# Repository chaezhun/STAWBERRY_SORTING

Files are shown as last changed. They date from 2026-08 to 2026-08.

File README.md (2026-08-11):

# Strawberry Sorting System

> Three embedded boards — different chips, different operating systems, different languages —
> tied into one sorting line.

A camera and an NPU classify strawberries moving along a conveyor as fresh, unripe or rotten,
and a rotating plate at the end of the belt discharges each class. The communication chain —
Ethernet TCP → IPC shared memory → CAN — was designed from scratch, and at two frames per
second with frequent misdetections the line still actuates **exactly once per strawberry**.
The whole line starts from a single SSH command; no UART cables remain.

[한국어](README.ko.md)

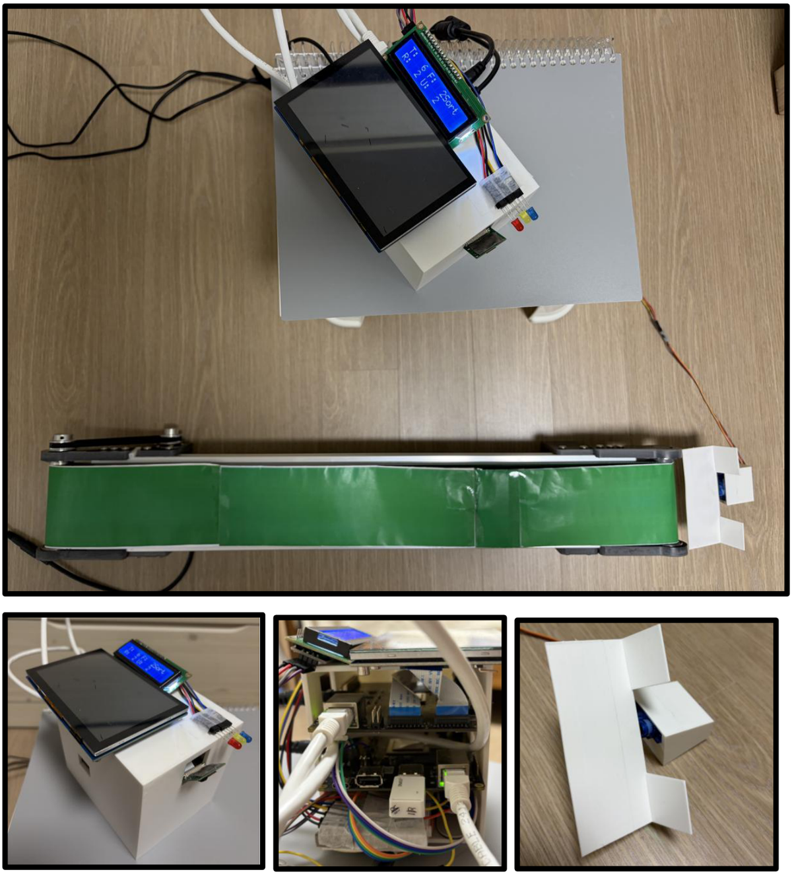
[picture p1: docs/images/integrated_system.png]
The assembled system — conveyor, rotation plate, control tower and status LCD


---

## Contents

- [Background](#background)
- [System](#system)
- [Design](#design)
- [Repository structure](#repository-structure)
- [Results](#results)
- [Build and run](#build-and-run)
- [Notes](#notes)

## Background

Each board owns a different layer. Recognition belongs on the NPU, decisions on Linux,
actuation on a real-time MCU. The problem was that the three can only speak in different ways.

AI-G runs a minimal Yocto image with no Python at all. D3-G has two cores running different
operating systems that must communicate through shared memory. VCP-G only accepts CAN frames.
Every hop uses a different mechanism, and making them mesh was most of the work.

## System

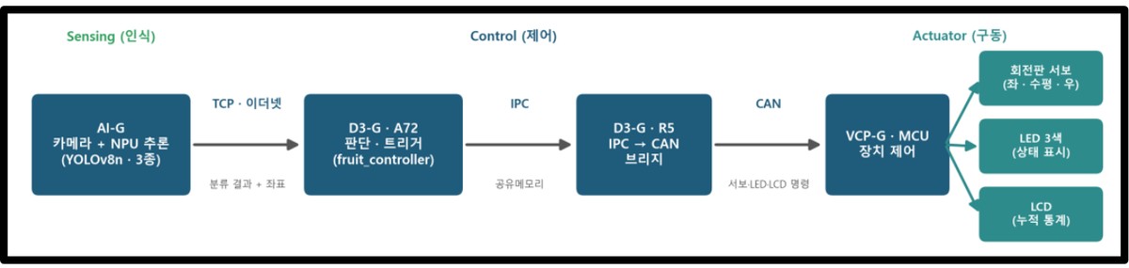
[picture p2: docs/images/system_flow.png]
End-to-end flow — the data path across the recognition, control and actuation boards


```
 camera --> [ AI-G ]  --Ethernet TCP-->  [ D3-G A72 ]
            YOLOv8n on                    classification gating, actuation timing
            the NPU                               |
                                                  | IPC shared memory
                                                  v
                                         [ D3-G R5, FreeRTOS ]
                                                  |
                                                  | CAN bus
                                                  v
                                         [ VCP-G ]  servo, LEDs, LCD
```

| Board | Role | Configuration |
|---|---|---|
| AI-G | Recognition | camera + NPU (8 TOPS), Yocto Linux, YOLOv8n |
| D3-G | Control | A72 (Linux) decides, R5 (FreeRTOS) relays shared memory onto CAN |
| VCP-G | Actuation | TCC70xx MCU, servo, three-colour LEDs, LCD |

With no Python on AI-G, result transmission is written in `sh` + `awk` + `nc`. The two D3-G
cores talk over `/dev/tcc_ipc_micom`, and from there to the actuation board it is CAN — one
byte for the servo angle, two for the LEDs, four for the LCD counter.

### Recognition model

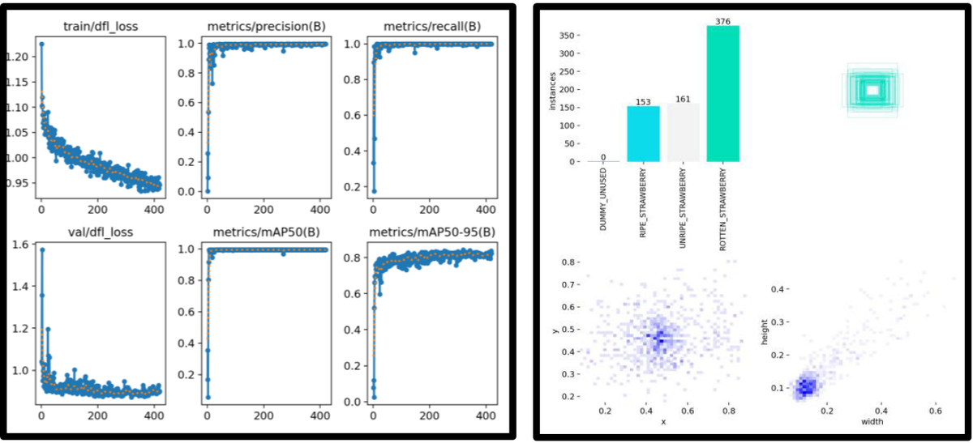
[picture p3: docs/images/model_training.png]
Training results — loss, precision, recall and mAP curves with the class distribution


YOLOv8n (about 3M parameters) was trained on a strawberry dataset we photographed and labelled
ourselves, reaching 0.99 validation mAP50. The lightweight model was chosen because the board
has 2 GB of memory. Dataset construction, training and NPU conversion were my teammate's work.

### Housing

| Exterior | Interior |
|---|---|
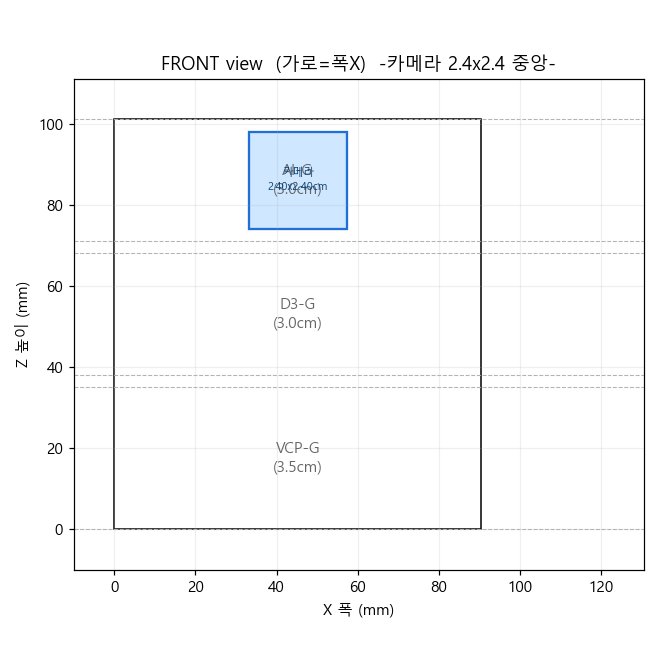
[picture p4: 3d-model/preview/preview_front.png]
Housing front
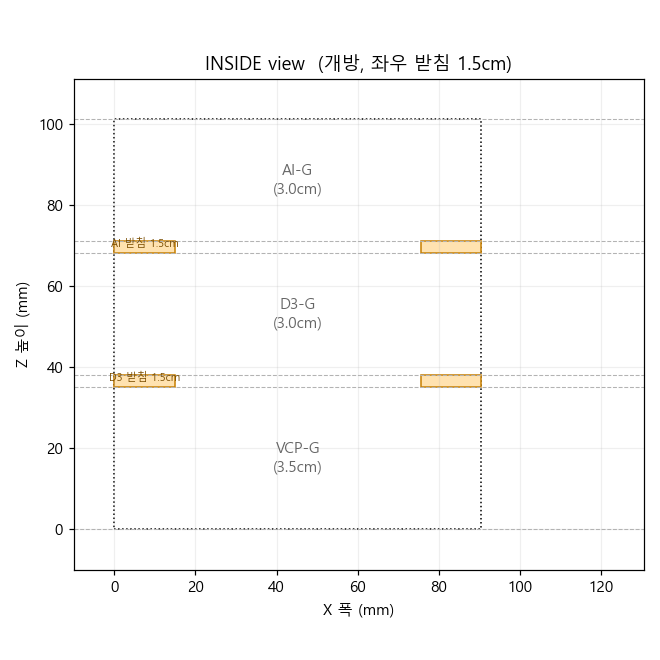
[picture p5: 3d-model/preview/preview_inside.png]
Housing interior
|  |  |

## Design

### Exactly once per strawberry

The camera runs at two frames per second and model misdetections are not negligible. Actuating
on detection means the plate turns several times for one strawberry, or turns for nothing on a
single frame of jittered coordinates. Five stages sit between detection and the servo.

| Stage | Rule |
|---|---|
| Confidence | ignore anything under 50% |
| Trigger box | both X and Y must fall inside the plate region |
| Debounce | three consecutive frames inside the box |
| Re-arm gap | that class must disappear for 1.5 s before it counts as a new strawberry |
| Non-blocking servo | triggers arriving mid-motion are dropped, not queued |

The last one came out of a failure. With a single plate, serialising servo calls behind a lock
meant excess triggers accumulated as 1.3-second motions and the plate kept turning over empty
belt long after the strawberry had passed. Making the lock non-blocking removed the backlog
rather than draining it.

### Three kinds of misdetection

A model with 0.99 validation mAP50 behaves differently over a real belt. The causes differ, so
the fixes did too.

| Problem | Cause | Fix |
|---|---|---|
| Detection too early and too twitchy | decision made on the Y coordinate alone | 2D box using both X and Y — accepted only right before the plate |
| Over-detection of unripe | most heavily represented in training, so detected every frame and triggering on box entry | a smaller box specific to unripe, with the entry edge moved inward |
| Fresh misclassified | fresh occasionally detected as rotten or unripe | one frame of fresh blocks other classes for 2 s |

That last fix came from watching the *direction* of the errors. Fresh being called defective
was common; defective being called fresh was rare. So the fresh signal is the trustworthy one,
and the logic is deliberately asymmetric: fresh fires on one frame while rotten and unripe
require three, so fresh always wins the race.

### The class that never appeared on the board

Every class was detected on the PC simulator, but class index 0 never came out on the board. My
teammate isolated it by comparing against the simulator, verifying MD5 sums and reading the raw
logs: tcnnapp's post-processing treats index 0 as background and drops it. The workaround was to
shift every training label up by one and leave class 0 empty
([`NPU_PIPELINE.md`](BOARD_CODE/ai-g/NPU_PIPELINE.md) §7).

That leaves the board emitting indices that no longer match the project's. The awk in the
result-sender script maps them back — **2 to fresh, 3 to unripe, 4 to rotten**, everything else
discarded — so the controller receives the original numbering. That is why the model directory
is named `strawberry_shifted_v2_quantized`.

### Cable-free operation

Originally every board needed its own UART and its own commands. Now the control code starts
recognition on AI-G over SSH and tears everything down after 30 seconds with no detection. One
command does it.

Along the way: AI-G's IP was made persistent across reboots with a systemd service,
passwordless SSH keys were set up between boards, and NetworkManager was stopped from wiping
the static IP with `nmcli managed no`. The assumption that R5 needed a manual `log on` was
re-tested with a cold power cycle and turned out to be false — that is how the last UART cable
went away. The line now runs from cold boot over WiFi alone.

### Tuning without reflashing

Reloading the actuation firmware means WSL build → boot mode → FWDN → reboot, every time. So
everything tuned in the field lives in the Python controller instead: the three rotation angles,
hold time, trigger box coordinates, debounce frame count, re-arm gap. Changing one means copying
a file and rerunning. The camera moved more than once and the boxes had to be re-measured, so
this structure paid for itself.

### What the hardware taught

The plate started on an MG90S, which turned out to be a continuous-rotation servo — speed is
controllable, position is not. Timing the angle drifted every run, so it was replaced with a
positional SG90 and the target angle is now sent directly over CAN.

The LCD lit its backlight but showed no characters, and an I2C scan returned 0x00 at every
address. Attaching a scanner to both ports found nothing; the cause was wiring. It was connected
to pins this board cannot route I2C on. Moving it to the proper header and matching the firmware
port fixed it.

During wireless operation the LEDs and CAN logs were fine but the motor would not turn. That
isolated the CAN/R5/VCP path as healthy, leaving the servo wiring — insulating tape caught in a
jumper joint.

### 3D-printed parts

All three parts were modelled in CadQuery with every dimension as a named constant, and printed
on a Bambu X1-Carbon.

| Rotation plate | Support |
|---|---|
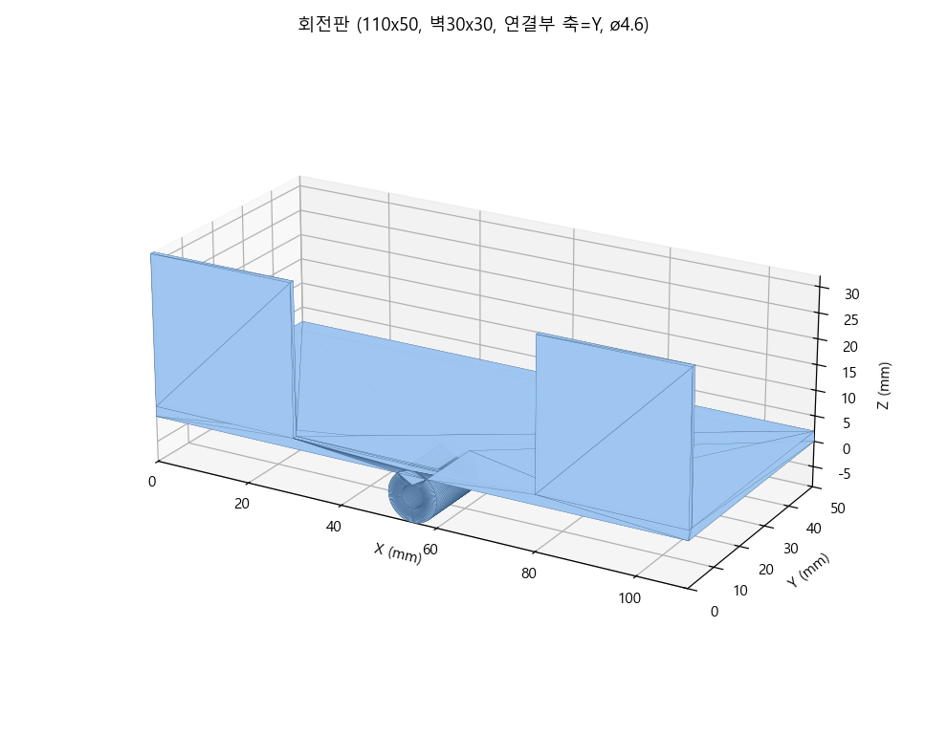
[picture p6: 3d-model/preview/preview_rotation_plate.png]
Rotation plate
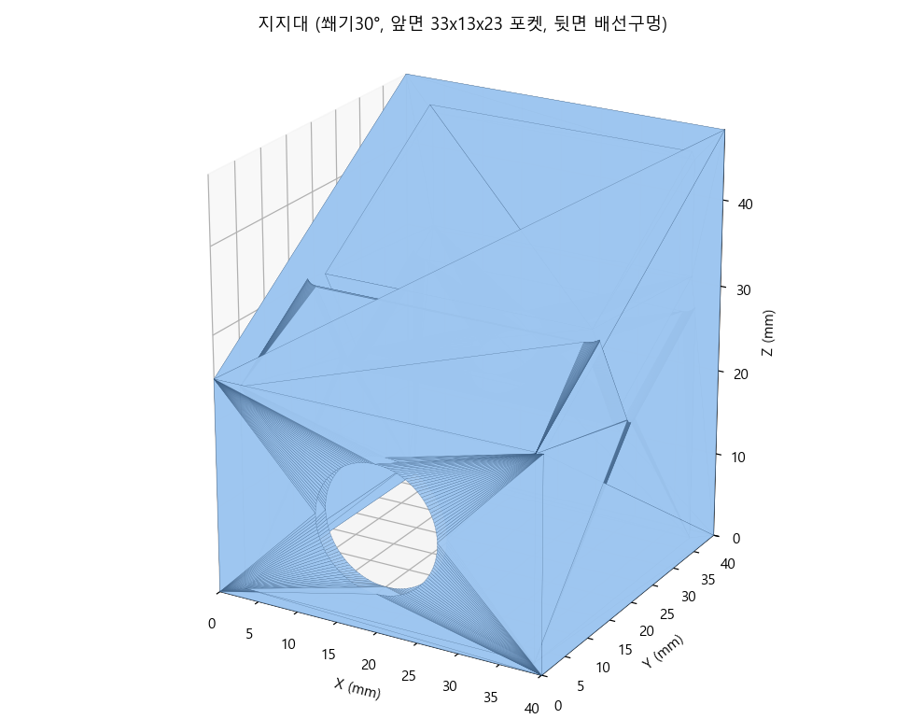
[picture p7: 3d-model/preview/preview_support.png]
Support
|  |  |

- **Housing** 96.5 × 123.5 × 107.0 mm, three boards on three shelves, with power, port and
  camera cutouts
- **Rotation plate** 110 × 50 × 1.3 mm with side walls, press-fits directly onto the SG90 spline
- **Support** holds the servo at 30 degrees to the ground so fresh strawberries roll through;
  includes a servo pocket and a wiring channel

The support was first modelled as a hollow shell, which produced a non-watertight solid the
slicer rejected. It became a watertight solid hollowed out by infill instead.

## Repository structure

```
BOARD_CODE/d3-g/
  fruit_controller.py        TCP server, classification gating, IPC transmission
  IPC_Example.py             IPC send CLI (A72 -> R5)
  IPC_Library.py             IPC packet construction + CRC16
BOARD_CODE/ai-g/
  ai_result_sender.sh        parses tcnnapp output -> TCP
  NPU_PIPELINE.md            training, conversion and deployment end to end
  sample_logs/               real detection logs per class
BOARD_CODE/vcp-g/
  app.can.demo/              CAN receive dispatch -> servo, LEDs, LCD
  app.base/                  entry point
  drivers/                   PWM, I2C/LCD, GPIO, CAN
  board_pinmap.md            GPIO names to physical connector pins
3d-model/
  model_file/                STEP and STL exports
  preview/                   renders of the three parts
docs/
  final_presentation_ko.pdf  final presentation
  final_report_ko.pdf        final report
  images/                    diagrams and operation screens taken from the final report
```

## Results

| | |
|---|---|
| Boards | three — 8 TOPS NPU (Yocto), dual-core control (Linux + FreeRTOS), MCU actuation |
| Communication | Ethernet TCP → IPC shared memory → CAN bus |
| Reliability | **exactly one actuation per strawberry** at 2 fps with frequent misdetections |
| Operation | whole line starts and stops from one SSH command; no UART cables |

### Operation

The result is shown immediately on three LEDs and an LCD — red for rotten, yellow for unripe,
green for fresh, all going dark after about a second. The LCD carries the idle state and the
running totals (all, fresh, rotten, unripe).

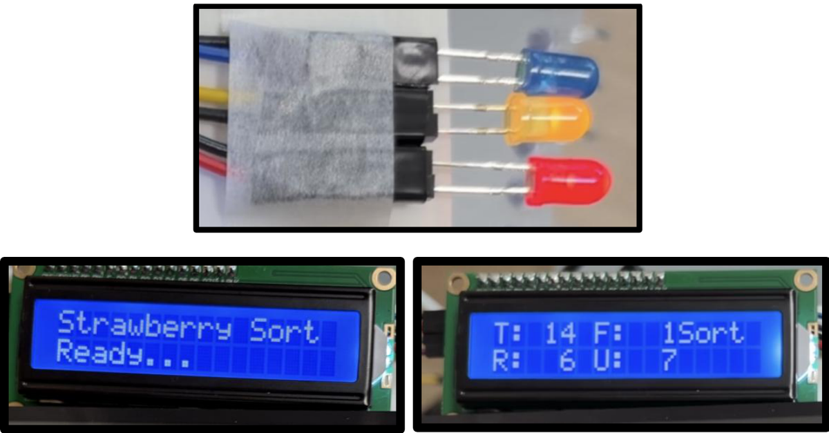
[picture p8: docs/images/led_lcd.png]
Three-colour LED indication and the LCD idle and totals screens


The run log after starting with a single command: the tuning constants, the fixed IP, the
automatic SSH start on AI-G, the TCP connection, and then detections with coordinates and
confidence.

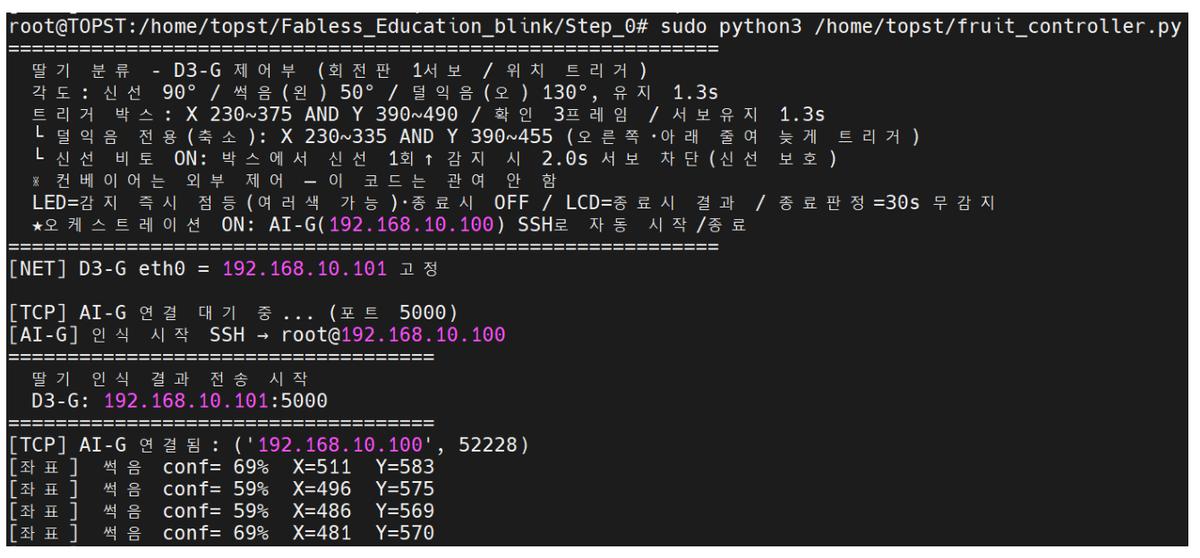
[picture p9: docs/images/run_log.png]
Run log in the D3-G SSH session


## Build and run

**Prerequisites** — the Telechips TOPST SDK for building VCP-G firmware (built under WSL),
Python 3 on D3-G, and the trained model deployed on AI-G.

1. **Actuation board** — build `BOARD_CODE/vcp-g/` with the SDK and flash it with FWDN. Only
   needed again when the pin map or CAN format changes; all tuning parameters live in the
   controller.
2. **Recognition board** — place the three model files in
   `/usr/share/strawberry_shifted_v2_quantized/` and copy `ai_result_sender.sh` to `/home/root/`.
   The conversion and deployment process is in
   [`NPU_PIPELINE.md`](BOARD_CODE/ai-g/NPU_PIPELINE.md).
3. **Control board** — run `sudo python3 fruit_controller.py` on D3-G. With
   `ORCHESTRATE = True` it fixes its own IP, starts recognition on AI-G over SSH, and tears
   everything down after 30 seconds with no detection.

One-time setup: a static IP on AI-G, and a passwordless SSH key from the control board to AI-G.

## Notes

**My part** — this was a two-person project. I worked on the control and actuation boards, the
communication chain, system integration, field tuning and the final documentation. My teammate
handled the dataset, YOLOv8n training and the NPU deployment pipeline (including
`NPU_PIPELINE.md`). The 3D modelling was joint work.

**Not included** — course materials and dataset images are distributed content and are excluded.

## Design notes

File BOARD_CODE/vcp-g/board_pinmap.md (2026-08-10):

# VCP-G pin map

Mapping between the firmware GPIO names (`GPA`/`GPB`/`GPC`/`GPK`) and the physical
connectors on the board, transcribed from the board pinout and checked against two
known-good references: `J8D102` pin 6 is `GPIO_A[13]`, matching the PWM example, and
`J8D102` pins 1-4 are `GPB25/28/11/27`, matching the GPIO example.

## Wiring used by this project

| Part | Firmware GPIO | Connector |
|---|---|---|
| Red LED (rotten) | `GPA(6)` | J8D104 pin 16 |
| Yellow LED (unripe) | `GPA(28)` | J8D104 pin 18 |
| Green LED (fresh) | `GPA(29)` | J8D104 pin 19 |
| Tilt plate servo | `GPB(7)` | J3D100 pin 1, with 5 V on pin 2 and ground on pin 6 |
| LCD SCL | `GPC(7)` | J10D100 SCL |
| LCD SDA | `GPC(6)` | J10D100 SDA |
| Conveyor enable | `GPB(2)` | J8D104 pin 21 |

`GPA(7)` sits on J8D104 pin 17, which does not drive on this board. The blue LED is
defined against it in the header but never used, and yellow was moved to pin 18 for
that reason.

The conveyor runs from an external PWM module with a manual speed knob. The board
only switches its power through a relay on the enable pin, so none of the old
direct-PWM motor pins are wired.

## Connectors

### J8D104 (purple, silk 14-21)

| Silk | GPIO |
|---|---|
| 14 | `GPIO_C[00]` |
| 15 | `GPIO_C[01]` |
| 16 | `GPIO_A[06]` |
| 17 | `GPIO_A[07]` |
| 18 | `GPIO_A[28]` |
| 19 | `GPIO_A[29]` |
| 20 | `GPIO_B[03]` |
| 21 | `GPIO_B[02]` |

### J8D102 (blue, silk 0-7)

| Silk | GPIO |
|---|---|
| 0 | `GPIO_B[26]` |
| 1 | `GPIO_B[25]` |
| 2 | `GPIO_B[28]` |
| 3 | `GPIO_B[11]` |
| 4 | `GPIO_B[27]` |
| 5 | `GPIO_B[10]` |
| 6 | `GPIO_A[13]` |
| 7 | `GPIO_B[01]` |

### J10D100 (light blue, I2C, silk 9-13)

| Silk | GPIO |
|---|---|
| SCL | `GPIO_C[07]` |
| SDA | `GPIO_C[06]` |
| AREF | `AD0[06]` |
| GND | ground |
| 13 | `GPIO_C[12]` |
| 12 | `GPIO_C[15]` |
| 11 | `GPIO_C[14]` |
| 10 | `GPIO_C[13]` |
| 9 | `GPIO_B[00]` |

### J8D101 (yellow, silk A0-A7)

| Silk | GPIO |
|---|---|
| A0 | `AD0[03]` |
| A1 | `AD0[04]` |
| A2 | `GPIO_C[02]` |
| A3 | `GPIO_C[03]` |
| A4 | `GPIO_C[05]` |
| A5 | `GPIO_C[04]` |
| A6 | `AD0[05]` |
| A7 | `AD0[01]` |

### J8D103 (green, silk A8-A11 and S4-S7)

| Silk | GPIO |
|---|---|
| A8 | `GPIO_C[08]` |
| A9 | `GPIO_C[09]` |
| A10 | `GPIO_C[10]` |
| A11 | `AD0[02]` |
| S4 | `GPIO_K[14]` |
| S5 | `GPIO_K[15]` |
| S6 | `GPIO_K[01]` |
| S7 | `GPIO_K[08]` |

### J3D100 (pink, 2x3)

| Pin | GPIO |
|---|---|
| 1 | `GPIO_B[07]` |
| 2 | `5P0_B` |
| 3 | `GPIO_B[04]` |
| 4 | `GPIO_B[06]` |
| 5 | `GPIO_B[05]` |
| 6 | ground |

### J5D100 (lavender, 2x5)

| Pin | GPIO | Pin | GPIO |
|---|---|---|---|
| 1 | `3P3_D` | 2 | `3P3_C` |
| 3 | `GPIO_K[09]` | 4 | `GPIO_K[01]` |
| 5 | `GPIO_K[08]` | 6 | `GPIO_K[02]` |
| 7 | `GPIO_K[07]` | 8 | `GPIO_K[03]` |
| 9 | ground | 10 | ground |

### J8D100 (red)

Power only: `3P3_A` as IOREF, `PORN` as reset, `3P3_B` at 3.3 V, `5P0_A` at 5 V, two
grounds, and VIN.

### J18D100 (large blue)

Even pins 22-52 and odd pins 23-53, with ground and `5P0_C` down the outer columns.
It carries most of the remaining `GPIO_A` lines plus `GPIO_K[11]`, `GPIO_K[13]` and
`GPIO_B[19..24]`. Nothing in this project is wired to it.

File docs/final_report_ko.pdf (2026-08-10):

### 고급프로젝트 최종 보고서

# 딸기 자동 분류 시스템

### AI 신선도 인식 기반 농산물 선별 자동화

TOPST SDV 3-Zone 임베디드 시스템 (AI-G · D3-G · VCP-G)

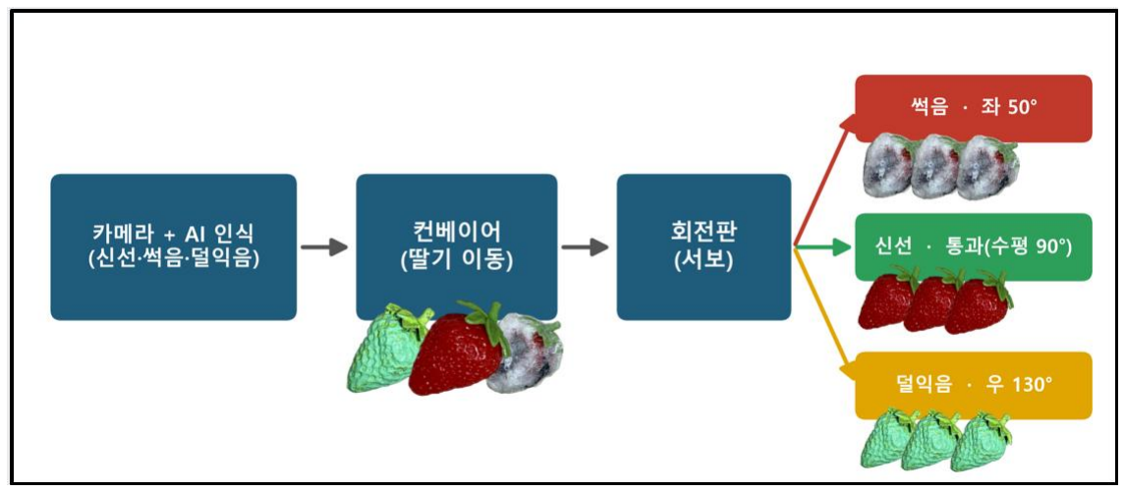
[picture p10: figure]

1 조

강요한 · 채지훈

중앙대학교 · 텔레칩스 팹리스 실무교육과정

## 0. 요약

딸기 자동 분류 시스템은 컨베이어 위를 지나는 딸기를 카메라와 AI(NPU)가 실시간으로

인식하여 신선·썩음·덜익음 3 종으로 판별하고, 끝단의 회전판이 종류별로 자동 분류하는

임베디드 시스템이다. 텔레칩스 자율주행 차량 키트의 인식 - 제어·통신 - 구동 구조에

착안하여, 칩과 운영체제, 프로그래밍 언어가 모두 다른 보드 세 개(AI-G·D3-G·VCP-G)를

이더넷·IPC·CAN 으로 연결하여 하나의 선별 라인으로 통합하였다.

AI 부문에서는 공개 데이터셋이 없는 한계를 모형 직접 제작·촬영으로 해결하여 539 장의

데이터셋을 구축하고, 경량 모델 YOLOv8n 을 학습하여 mAP50 약 0.99 를 달성하였다.

ONNX 변환·INT8 양자화·컴파일 파이프라인으로 NPU 에 배포하는 과정에서 보드가 class

0 을 무시하는 버그를 발견하여 라벨 +1 shift 로 우회하였다. 제어 부문에서는 실제

환경에서 발생하는 오검출과 노이즈를 감지 박스·디바운스·gap 재무장·비차단 서보의

다단계 로직으로 보정하여 "딸기 1 개당 정확히 1 회 동작"을 구현하였으며, PC 에서 SSH 한

줄로 전체 시스템을 무선 기동·종료하는 운영 체계를 완성하여 세 보드의 풀체인 동작을

검증하였다.

## 1. 프로젝트 개요

### 1.1 배경 및 목표

농산물 선별은 신선도 판별과 물리적 분류가 모두 요구되는 노동집약적 공정이다. 본

프로젝트는 이 과정을 사람의 개입 없이 자동화하는 것을 목표로 하며, 나아가 딸기를

대상으로 스마트 팩토리형 선별 라인을 시험 제작하는 데 의의가 있다. 카메라 영상에서

AI 가 신선도를 판별하고, 기계가 종류별로 물리 분류하는 완결형 선별 라인을 임베디드

환경에서 구현하였다.

### 1.2 시스템 콘셉트

왼쪽에서 카메라와 AI 가 딸기를 인식하고, 컨베이어를 거쳐, 끝단의 회전판이 썩음은

좌(50 도), 덜익음은 우(130 도), 신선은 수평(90 도) 통과로 분류한다. 분류 결과는 LED 3 색과

LCD 누적 통계로 표시된다.

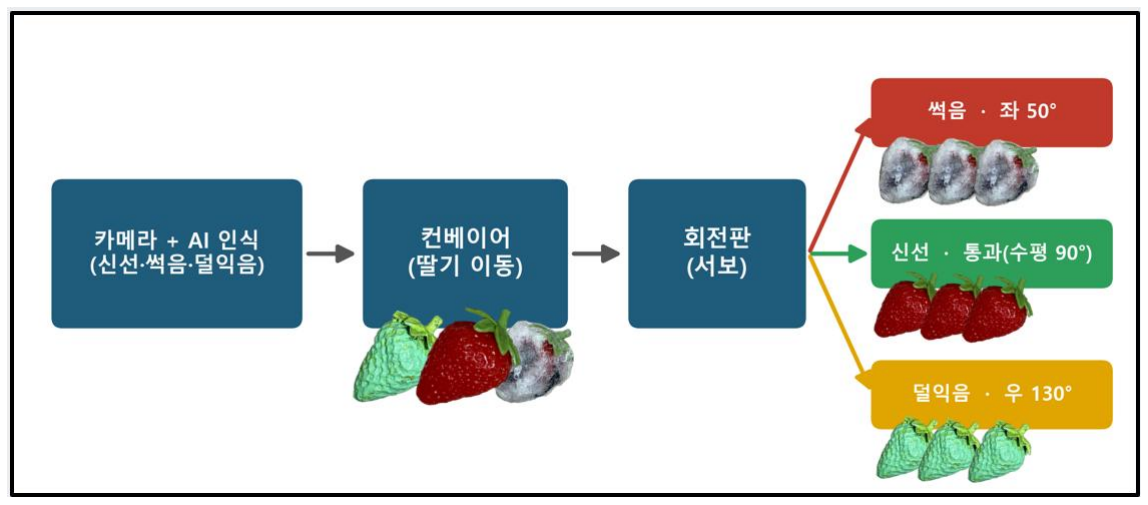
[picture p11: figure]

그림 1. 전체 동작 콘셉트 — 카메라·AI 인식, 컨베이어 이동, 회전판의 종류별 분류로 이어지는 흐름

### 1.3 역할 분담

담당 | 보드 / 영역 | 주요 작업
강요한 | AI-G (인식) | 데이터셋 구축, YOLOv8n 학습, NPU 변환·양자화·배포, 추론 연동, 발표
채지훈 | D3-G · VCP-G (제어·구동), 시스템 통합 | TCP 수신·분류 판단, IPC-CAN 브리지, 서보·LED·LCD 제어, 시스템 통합, 무선 운영, 실환경 튜, 통신 체인 연결, 발표 ppt,대본 제작
공동 | 뼈대 제작 | 3D 모델링·출력

## 2. 시스템 아키텍처

2.1 3-Zone 구성

역할이 다른 TOPST 교육 보드 세 개가 인식·제어·구동을 분담한다. 세 보드는 칩과 운영체제,

프로그래밍 언어가 모두 다르며, 이러한 이질적 보드를 하나로 통합하는 과정이 본

프로젝트의 핵심 난이도였다.

보드 | 역할 | 구성 및 핵심 기능
AI-G | 인식 (Sensing) | 카메라 + NPU(8 TOPS). YOLOv8n 추론 후 결과를 TCP 로 전송. Yocto Linux (Python 미탑재)
D3-G | 제어 (Control) | A72(Linux)가 판단·트리거, R5(FreeRTOS)가 IPC-CAN 브리지. 듀얼코어
VCP-G | 구동 (Actuator) | TCC70xx MCU. CAN 수신 후 회전판 서보·LED 3 색·LCD 제어

컨베이어 DC 모터는 어느 보드도 제어하지 않으며, 외부 전원과 컨트롤러로 별도

구동된다(속도 포함).

### 2.2 통신 체인과 데이터 흐름

카메라 인식 결과는 구간마다 다른 매체를 거쳐 액추에이터까지 전달된다. 이더넷(TCP) -

IPC(공유메모리) - CAN 으로 이어지는 3 단 체인 구조이다.

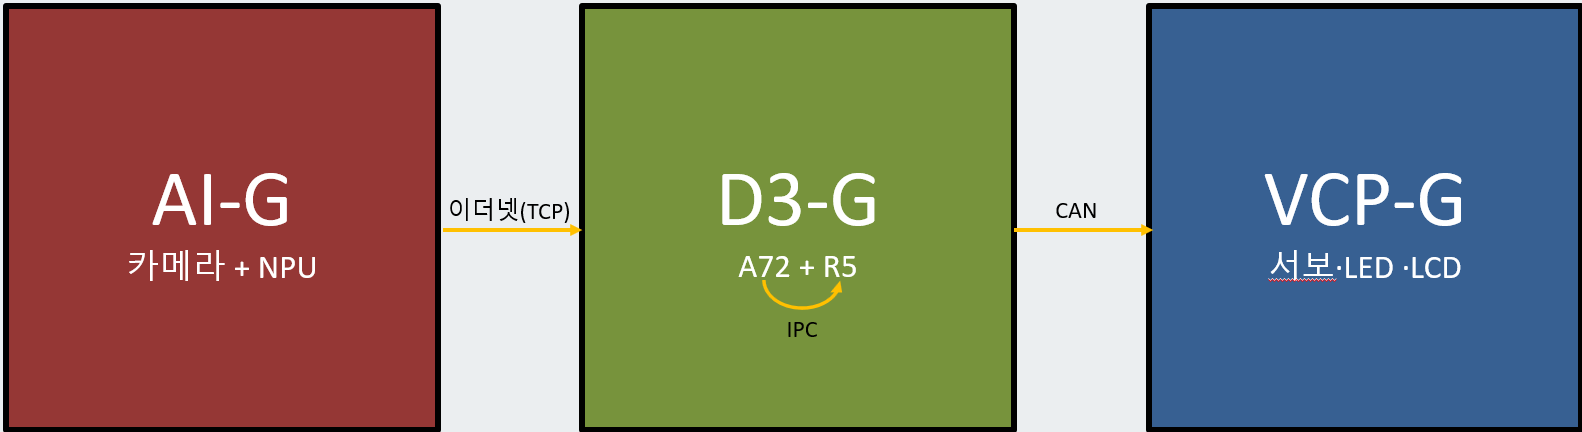
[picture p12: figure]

그림 2. 통신 체인 — 인식(AI-G)에서 제어(D3-G)를 거쳐 구동(VCP-G)으로 이어지는 이더넷·IPC·CAN

데이터 흐름

구간 | 매체 | 형식 / 비고
AI-G - D3-G(A72) | 이더넷 (TCP) | 포트 5000. CLASS,CONF,X,Y 문자열 (bbox 중심 좌표)
A72 - R5 | IPC 공유메모리 | /dev/tcc_ipc_micom, snd 모드 패킷
R5 - VCP-G | CAN Bus | 0x111 서보(각도), 0x114 LED, 0x116 LCD
컨베이어 | 외부 배선 | 보드 비관여 (외부 컨트롤러)

### 2.3 AI-G - D3-G 메시지 프로토콜 (TCP)

줄 단위 문자열을 포트 5000 으로 전송한다.

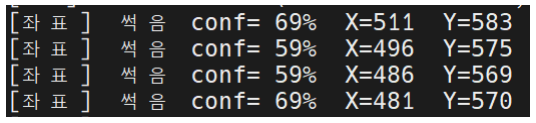
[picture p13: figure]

코드 1. AI-G - D3-G TCP 메시지 형식

필드 | 의미 | 비고
CLASS | 프로젝트 클래스 (0~2) | 0=신선, 1=썩음, 2=덜익음
CONF | 신뢰도 (%) | MIN_CONFIDENCE 미만은 D3-G 에서 무시
X, Y | bbox 중심 좌표 (원본 px) | 위치 트리거에 사용 (좌표가 곧 위치)
W, H | 미사용 | 현재 0 고정

### 2.4 네트워크 구성

연결 | IP / 포트 | 용도
AI-G eth | 192.168.10.100 | D3-G 와 이더넷 통신 (클라이언트)
D3-G eth | 192.168.10.101 : 5000 | AI-G - D3-G TCP 서버
D3-G (WiFi/USB) | 192.168.0.x | PC 에서 SSH 원격 운영 / SCP

## 3. AI 학습 및 NPU 배포

담당: 강요한. 데이터셋 구축부터 학습, NPU 양자화, 보드 배포·추론까지를 다룬다. 전체

변환은 강의안의 YOLOv8 워크플로를 따르되 모델만 딸기 모델로 교체하였다. 변환 명령어

전문은 부록 A 에, 변환 과정에서의 트러블슈팅은 부록 C·D 에 정리하였다.

### 3.1 데이터셋 구축

딸기 신선도에 적합한 공개 데이터셋이 존재하지 않아, 신선·덜익음·썩음 모형을 직접

제작하고 다양한 거리와 각도에서 촬영한 뒤 LabelImg 로 라벨링하여 총 539 장(train 475,

valid 64)의 데이터셋을 구축하였다. 촬영 환경 단위로 학습·검증 세트를 분리하여 데이터

누수를 방지하였다.

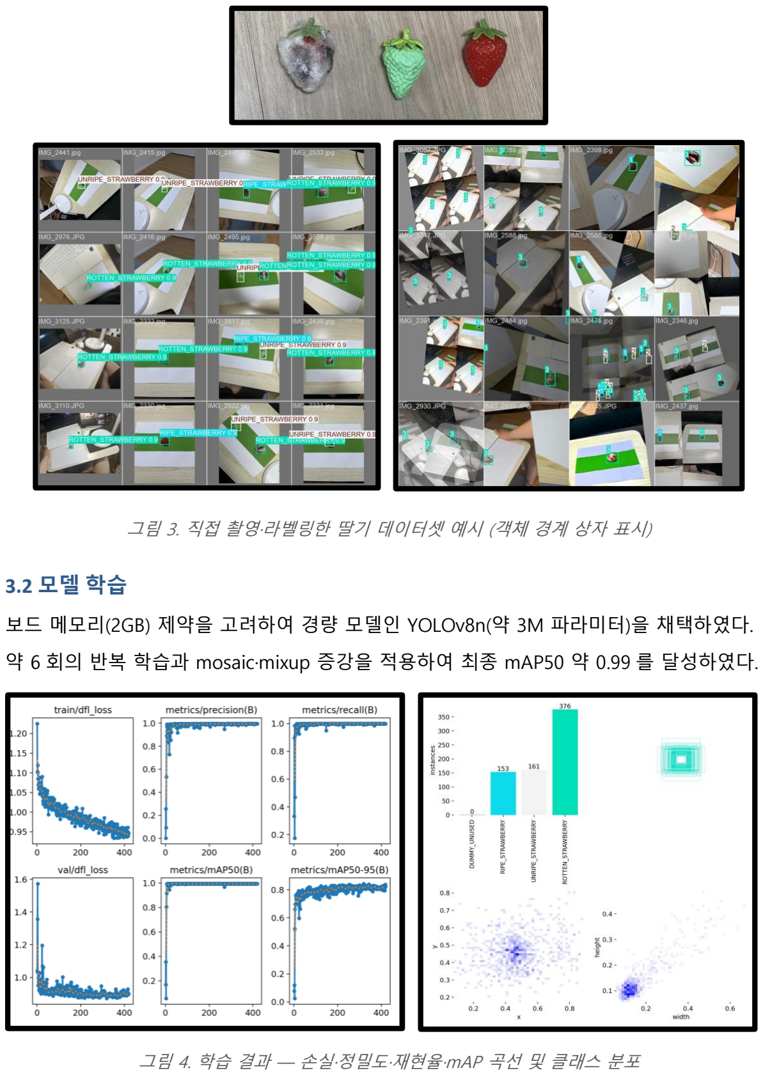
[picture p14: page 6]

그림 3. 직접 촬영·라벨링한 딸기 데이터셋 예시 (객체 경계 상자 표시)

### 3.2 모델 학습

보드 메모리(2GB) 제약을 고려하여 경량 모델인 YOLOv8n(약 3M 파라미터)을 채택하였다.

약 6 회의 반복 학습과 mosaic·mixup 증강을 적용하여 최종 mAP50 약 0.99 를 달성하였다.

그림 4. 학습 결과 — 손실·정밀도·재현율·mAP 곡선 및 클래스 분포

### 3.3 NPU 변환 및 배포

YOLOv8 의 후처리(DFL, NMS, sigmoid)는 NPU 에서 비효율적이므로, 백본·넥·헤드의 raw

합성곱 출력까지만 NPU 에서 연산하고 후처리는 CPU 에서 수행하도록 분리하였다. 이후

FP32 변환과 INT8 양자화, 컴파일을 거쳐 보드에 배포하였으며, 변환 결과 NPU 호환

레이어가 100%(미지원 0 개)로 확인되었다. 보드에서는 tcnnapp 를 통해 약 2 FPS 로

추론한다.

### 3.4 핵심 발견 — NPU class 0 버그와 라벨 +1 Shift

PC 시뮬레이터에서는 모든 클래스가 정상적으로 검출되었으나, 보드에서만 class 0 이

검출되지 않는 현상이 발생하였다. 이를 해결하기 위해 학습 라벨 전체를 1 씩 이동시켜

class 0 을 비워두는(DUMMY) 방식으로 우회하고, 클래스 수를 4 로 지정하여

재학습·변환하였다.

그 결과 최종 tcnnapp 출력은 한 칸 더 밀려 class 2 가 신선, class 3 이 덜익음, class 4 가

썩음으로 나타나며, 제어부의 ai_result_sender.sh 가 이 값을 프로젝트 클래스로 매핑한다.

이 발견은 검증 환경(PC)과 실행 환경(보드)의 차이를 드러낸 사례이다.

tcnnapp 출력 | 의미 | 프로젝트 클래스 / 동작
class 2 | fresh | 신선 / 수평 90 도 통과
class 3 | unripe | 덜익음 / 우 130 도
class 4 | rotten | 썩음 / 좌 50 도
그 외 | dummy 등 | 무시

## 4. 제어 및 시스템 통합

D3-G 가 AI 결과를 받아 분류를 판단하고, CAN 을 통해 VCP-G 의 회전판·LED·LCD 를

구동한다. 모든 분류 파라미터를 코드 상수로 분리하여 재플래싱 없이 즉시 조정할 수

있도록 설계하였다.

### 4.1 회전판 서보 — 분류 동작

분류 | 게이트는 | SG90 | 위치제어 | 서보 | 1 | 개로 | 구현하였다. | 초기에 | 사용한

연속회전형(MG90S)은 시간제어 방식이라 정지 위치가 일정하지 않아, 목표 각도로 정확히

멈추는 위치제어형(SG90)으로 교체하였다. 각도와 유지시간은 fruit_controller.py 상수로

분리되어 재실행만으로 튜닝된다.

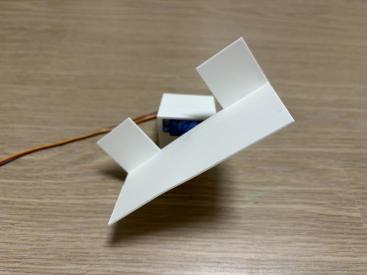
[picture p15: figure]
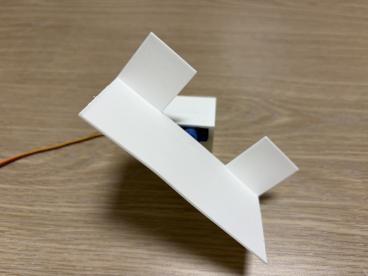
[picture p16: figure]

그림 5. 회전판(분류 게이트) — SG90 서보에 직결되어 좌·우·수평으로 기울어 종류별 배출

클래스 | 회전판 각도 | 동작 | LED
신선 | 수평 90 도 | 유지 후 통과 | 초록
썩음 | 좌 50 도 | 기울임 후 1.3 초 뒤 90 도 복귀 | 빨강
덜익음 | 우 130 도 | 기울임 후 1.3 초 뒤 90 도 복귀 | 노랑

신호 사양(위치제어 SG90): 주기 20ms(50Hz), 듀티 = 0.5ms + 각도×(2ms/180 도).

0 도=0.5ms, 90 도=1.5ms, 180 도=2.5ms 이며, 위치제어 서보에서는 듀티가 곧 물리 각도에

대응한다.

### 4.2 CAN ID 체계 (D3-G - VCP-G)

CAN ID | 기능 | 데이터 형식
0x111 | 회전판 서보 | byte0 = 목표 각도(0~180 도), 1 바이트 (90 도=5A)
0x114 | LED 제어 | byte0 = LED_ID, byte1 = ON(01)/OFF(00)
0x116 | LCD 통계 | byte0~3 = total, fresh, rotten, unripe (4 바이트)

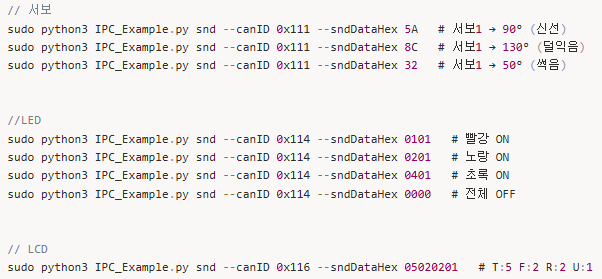
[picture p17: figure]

코드 2. IPC 를 통한 CAN 전송 예시 — 서보(0x111)·LED(0x114)·LCD(0x116) 명령

LED ID 매핑(0x114, byte0)은 0x00 ALL OFF, 0x01 RED(썩음), 0x02 YELLOW(덜익음), 0x04

GREEN(신선)이며, 바이트 길이를 엄수한다.

### 4.3 LED 및 LCD 표시

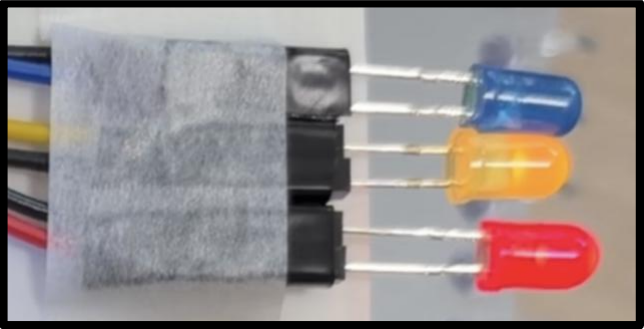
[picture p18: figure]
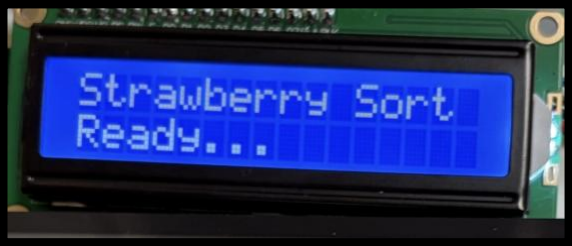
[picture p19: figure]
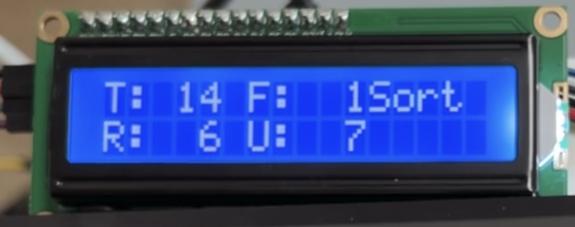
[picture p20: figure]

그림 6. 분류 결과 표시 — LED 3 색 점등과 LCD 대기·누적 통계 화면

분류 결과는 LED 3 색과 LCD 로 즉시 시각화된다. LED 는 썩음을 빨강, 덜익음을 노랑,

신선을 초록으로 표시하며, 분류와 동시에 점등된 뒤 약 1 초 후 소등된다. 색마다 독립

타이머로 동작하므로 여러 색이 동시에 점등될 수 있다. LED 제어는 회전판 모터 동작을

방해하지 않도록 논블로킹(백그라운드) 방식으로 처리하여 분류 동작에 항상 우선순위를

두었다. LCD 에는 분류 누적 통계(전체·신선·썩음·덜익음 개수)가 표시되며, 분류 세션이

종료(30 초 무감지 또는 종료 명령)되면 최종 통계를 보여준다.

### 4.4 분류 신뢰성 로직 — "딸기 1 개당 정확히 1 회"

카메라가 약 2 FPS 로 느리고 NPU 노이즈(좌표 점프 유령, 구석에 멈춘 유령, 오분류)가 많아,

단순히 "감지하면 바로 동작"하는 방식으로는 신뢰성이 부족하였다. fruit_controller.py 는

다음 파이프라인을 통해 한 딸기를 정확히 한 번만 분류한다.

단계 (상수) | 역할
신뢰도 필터 | MIN_CONFIDENCE=50 미만 무시
2D 박스 게이트 | TRIGGER_X 230~375 AND TRIGGER_Y 390~490 — 회전판 자리만. 덜익음만 축소 박스(X_HI 335 / Y_HI 455)로 늦게 트리거
신선 우선 | FRESH_VETO — 박스 안에서 신선이 1 프레임이라도 잡히면 그 딸기를 신선으로 간주, 2.0 초간 모터 차단
디바운스 | TRIGGER_CONFIRM=3 — 연속 3 프레임 잡혀야 인정 (1~2 프레임 유령 무시)
gap 설정 | COUNT_GAP=1.5 초 — 사라졌다 다시 와야 새 딸기로 인정 (중복 카운트 방지)
비차단 서보 | _servo_lock(non-blocking) — 동작 중 들어온 트리거는 건너뜀 (백로그 방지)
LED / 종료 | led_pulse 1.0 초 점등, end_watcher 30 초 무감지 시 LCD 통계 표시 후 종료

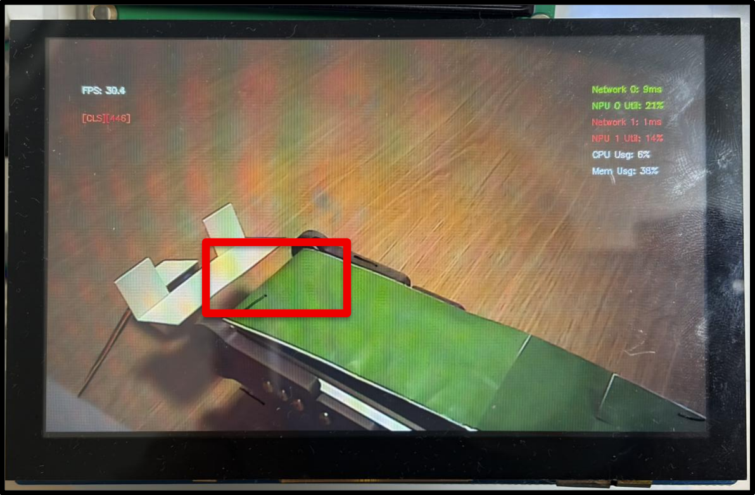
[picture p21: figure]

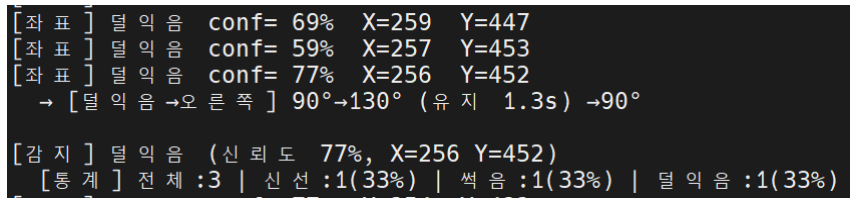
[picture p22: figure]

그림 7. 감지 박스(빨간 영역)와 이에 대응하는 D3-G 분류 로그 (좌표·신뢰도·누적 통계)

### 4.5 튜닝 상수 (재실행만으로 조정, 재플래싱 불필요)

상수 | 값 | 의미
SERVO_DEFAULT/LEFT/RIGHT_DEG | 90 / 50 / 130 | 수평 / 썩음(좌) / 덜익음(우)
SERVO_HOLD_TIME | 1.3 | 기울임 유지(초) 후 복귀
TRIGGER_X_LO~HI / Y_LO~HI | 230~375 / 390~490 | 감지 박스 좌표
TRIGGER_*_UNRIPE | X_HI 335 / Y_HI 455 | 덜익음 전용 축소 박스
FRESH_VETO_TIME | 2.0 | 신선 보호 차단 시간(초)
TRIGGER_CONFIRM / COUNT_GAP | 3 / 1.5 | 디바운스 / gap 재무장
MIN_CONFIDENCE / LED_ON_TIME | 50 / 1.0 | 신뢰도 하한 / LED 점등(초)
END_SESSION_TIMEOUT | 30 | 무감지 자동 종료(초)

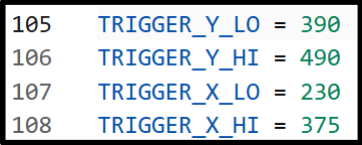
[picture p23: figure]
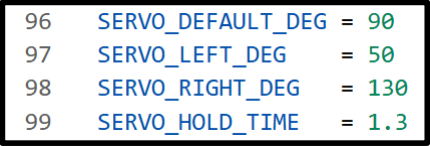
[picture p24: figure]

그림 8. 코드 상수로 분리한 튜닝 파라미터 (서보 각도·트리거 박스 좌표 등)

### 4.6 핀맵 (VCP-G firmware - 보드 헤더)

장치 | 종류 | firmware 핀 / 채널 | 보드 위치
LED RED (썩음) | GPIO | GPA(6) | J8D104 핀 16
LED YELLOW (덜익음) | GPIO | GPA(28) | J8D104 핀 18
LED GREEN (신선) | GPIO | GPA(29) | J8D104 핀 19
회전판 서보 (SG90) | PDM | ch1, PERICH_CH1 - GPB(7) | J3D100 핀 1
LCD | I2C | CH3 / PORT7, ADDR 0x27 | J10D100 GPC6/7

### 4.7 무선 통합 운영

PC 에서 D3-G 에 WiFi SSH 로 fruit_controller.py 한 줄을 실행하면 AI-G 인식이 자동

기동되고, 30 초 무감지 시 전체가 자동 종료된다. AI-G IP 영구화(systemd)와 무비밀번호

SSH 키 설정으로 PC 연결 케이블(UART, USB-C)을 모두 제거하고, WiFi SSH 만으로

콜드부팅부터 운영까지 동작함을 확인하였다.

코드 3. 무선 한 줄 운영 명령 — D3-G 가 AI-G 를 자동 지휘

## 5. 집중한 부분 — 실환경 문제와 해결

mAP 0.99 의 검증 점수에도 불구하고, 실제 환경에서는 카메라의 느린 속도와 다양한 각도,

노이즈로 인해 오검출이 발생하였다. AI 가 완전히 막을 수 없는 부분을 제어 로직으로

보정한 것이 본 프로젝트에서 가장 공들인 지점이다.

핵심은 세 가지 보정 로직이며, 각 코드의 역할은 다음과 같다. 첫째, 2D 감지 박스(코드 4)는

검출된 좌표가 회전판 직전의 지정 영역(X·Y 범위) 안에 들어올 때만 트리거하여 너무

이르거나 예민한 동작을 막는다. 둘째, 덜익음 전용 축소 박스(코드 5)는 과검출되는 덜익음

클래스에 한해 박스를 작게 잡아(오른쪽·아래 경계를 안쪽으로) 트리거 시점을 늦춰 다른

클래스와 타이밍을 맞춘다. 셋째, 신선 우선(코드 6)은 박스 안에서 신선이 한 번이라도

잡히면 일정 시간 서보와 카운트를 차단하여, 신선 딸기가 썩음·덜익음으로 오분류되어 잘못

배출되는 것을 방지한다.

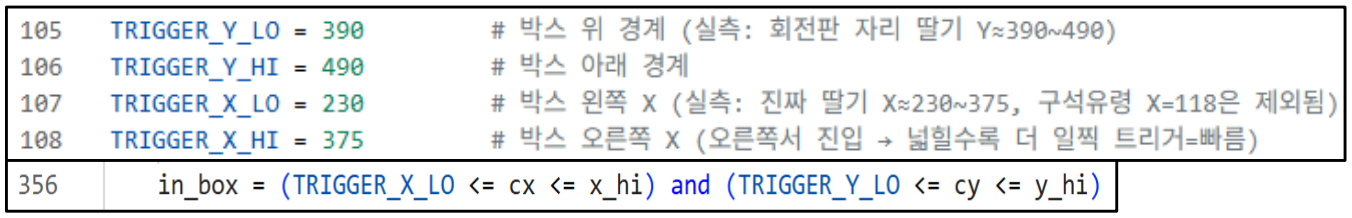
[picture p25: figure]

코드 4. 2D 감지 박스 게이트 — 검출 좌표가 박스 영역(X·Y) 안일 때만 트리거

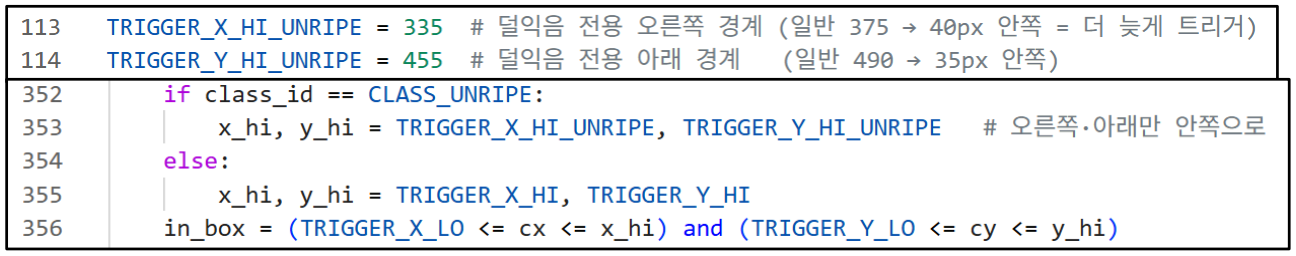
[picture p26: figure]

코드 5. 덜익음 전용 축소 박스 — 클래스별로 트리거 영역을 다르게 적용

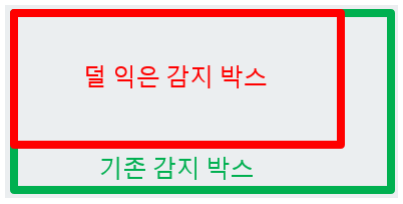
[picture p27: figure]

그림 9. 감지 박스 비교 — 기존 박스(초록)와 덜익음 전용 축소 박스(빨강)

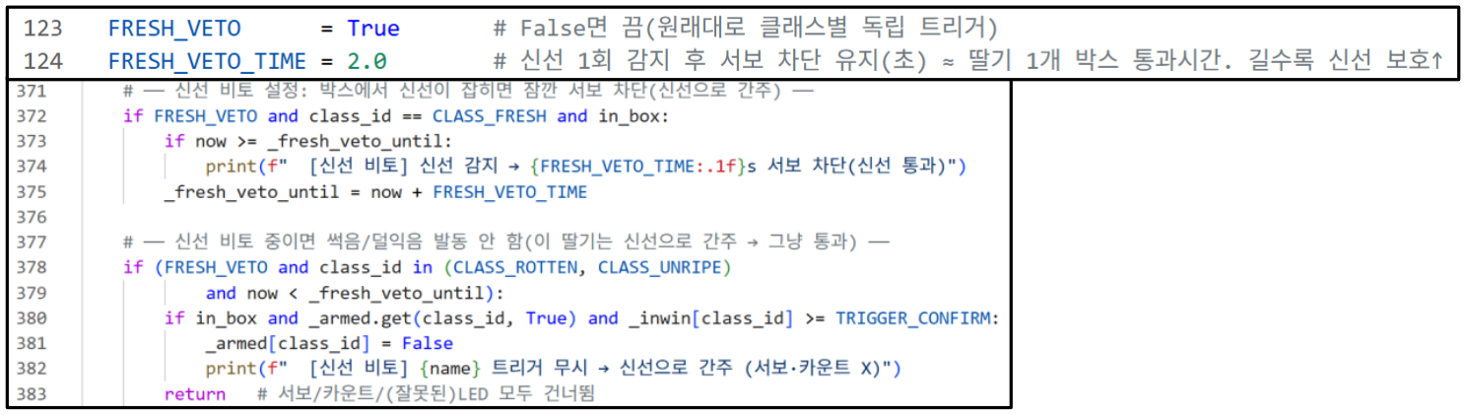
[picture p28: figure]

코드 6. 신선 우선(FRESH_VETO) — 박스에서 신선이 잡히면 서보·카운트를 건너뜀

문제 | 원인 | 해결
너무 빠르고 예민한 감지 | 초기에는 Y 좌표만으로 판단 | X·Y 2D 감지 박스 도입 — 회전판 자리에 왔을 때만 트리거
덜익음 과검출 | 덜익음 학습량이 많아 과검출 | 덜익음만 감지 박스를 축소 — 트리거를 늦춰 타이밍 정합
신선 오분류 | 신선이 가끔 썩음/덜익음으로 오검출 | 신선 우선(FRESH_VETO) — 신선이 1 회라도 잡히면 그 딸기는 신선으로 우선 처리

- 신선 우선의 근거: 모델은 신선을 썩음·덜익음으로 오분류하는 경우는 잦으나,

반대로 썩음·덜익음을 신선으로 오분류하는 경우는 드물다. 따라서 신선 신호를

신뢰하여, 박스 안에서 신선이 한 번이라도 잡히면 그 딸기를 신선으로 간주하고

모터 동작을 차단함으로써 신선 딸기의 오배출을 방지하였다. 신선은 1 프레임,

썩음·덜익음은 3 프레임을 요구하도록 비대칭 설계하여 신선이 우선되도록 하였다.

- 튜닝의 코드화: 서보 각도와 유지시간, 감지 박스 좌표, 디바운스, gap 등 모든 값을

코드 상수로 분리하여 재플래싱 없이 즉시 조정할 수 있게 하였다. 이는 반복적인

현장 튜닝의 생산성을 크게 향상시켰으며, 본 시스템이 다양한 환경 변화에 빠르게

대응할 수 있는 기반이 되었다.

## 6. 결과물

6.1 3D 모델링

보드 수납 케이스와 분류 기구를 Python 파라메트릭 모델링으로 직접 설계하여

출력하였다(Bambu X1-Carbon).

- 컨트롤 타워: AI-G·D3-G·VCP 보드 3 개를 3 층으로 적층 수납하는 통합 하우징
- 회전판: SG90 에 직결되어 좌·우·수평으로 기울어 종류별로 배출
- 지지대: 회전판을 지면과 30 도 경사로 받쳐, 신선 딸기가 그대로 굴러 통과

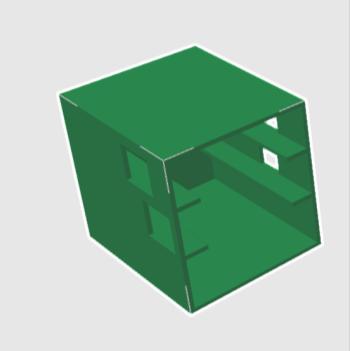
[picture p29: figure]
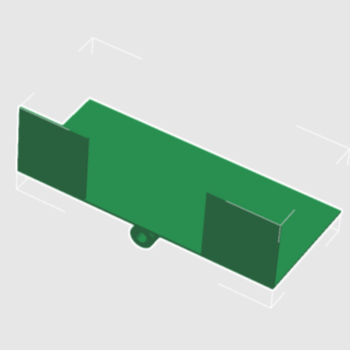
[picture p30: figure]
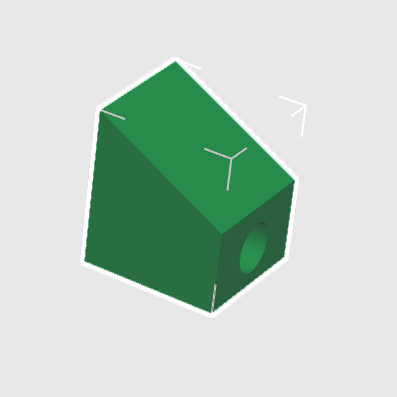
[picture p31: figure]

그림 10. 직접 모델링·출력한 기구물 — 컨트롤 타워, 회전판, 30 도 경사 지지대

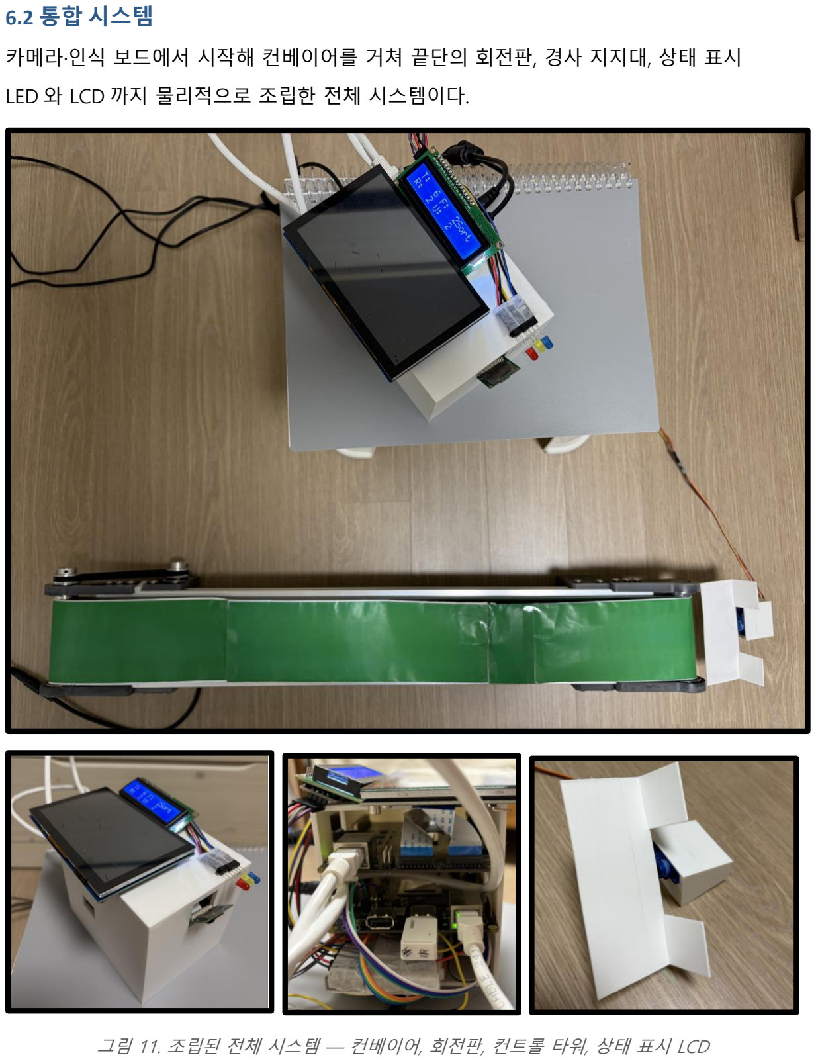
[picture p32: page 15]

### 6.2 통합 시스템

카메라·인식 보드에서 시작해 컨베이어를 거쳐 끝단의 회전판, 경사 지지대, 상태 표시

LED 와 LCD 까지 물리적으로 조립한 전체 시스템이다.

그림 11. 조립된 전체 시스템 — 컨베이어, 회전판, 컨트롤 타워, 상태 표시 LCD

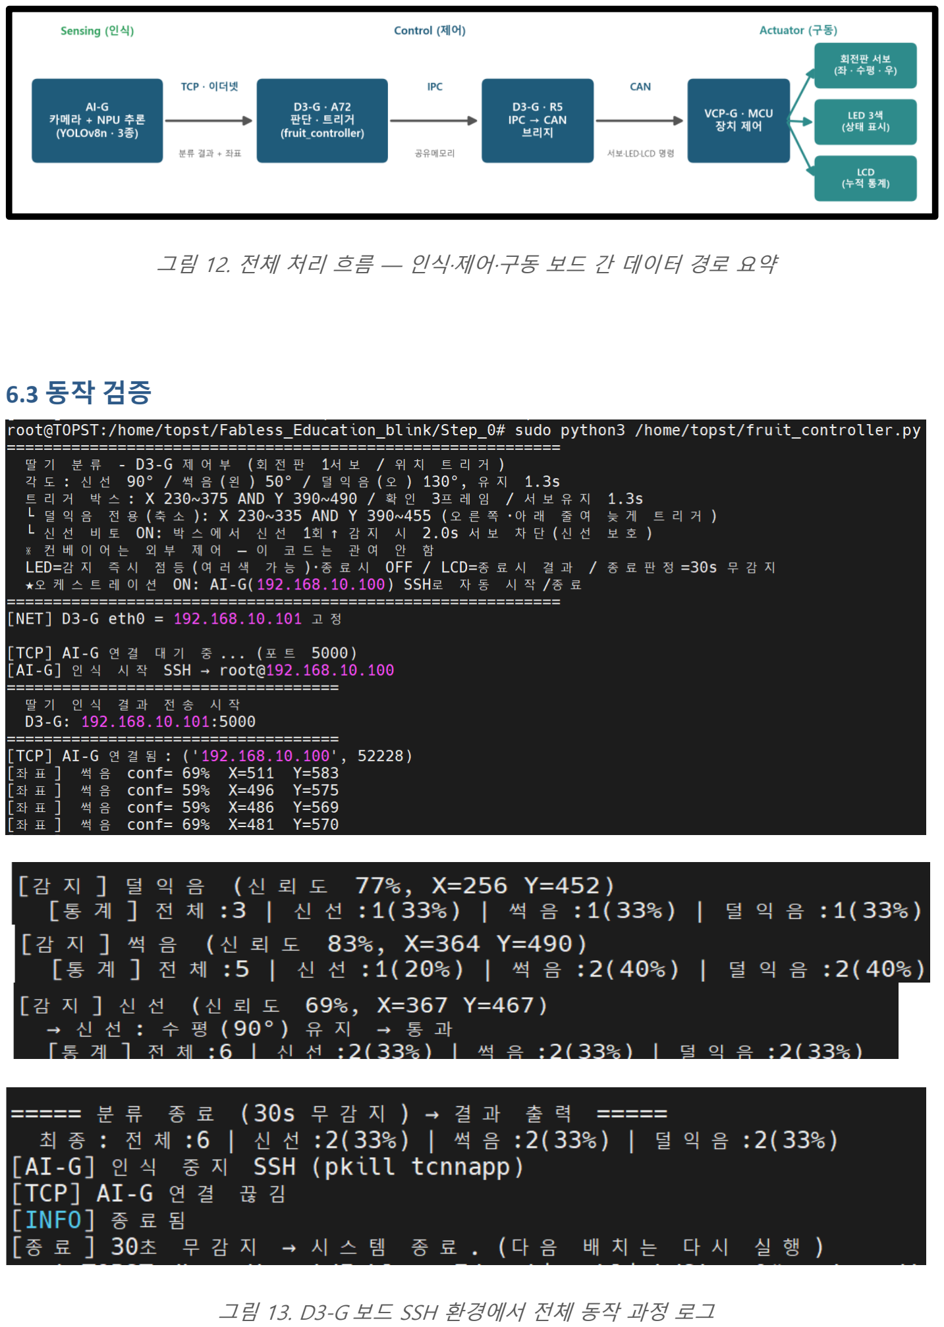
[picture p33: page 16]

그림 12. 전체 처리 흐름 — 인식·제어·구동 보드 간 데이터 경로 요약

### 6.3 동작 검증

그림 13. D3-G 보드 SSH 환경에서 전체 동작 과정 로그

AI-G 카메라 추론, D3-G 박스 트리거, VCP 서보·LED·LCD 까지 세 보드의 풀체인 동작을

확인하였으며, 실제로 딸기를 흘려보내 분류가 이루어짐을 검증하였다. LED 멀티 점등, LCD

통계 표시, 30 초 무감지 자동 종료, PC SSH 한 줄 무선 기동까지 모두 정상 동작함을

확인하였다.

## 7. 발전 가능성 및 결론

### 7.1 발전 가능성

항목 | 현재 구현 | 발전 방향
처리량 | 딸기가 하나씩 간격을 두고 이동 | 여러 개가 동시·밀집하여 와도 정확히 분류 (다중 객체 인식·제어 정교화)
속도 | 컨베이어 이동이 느림 | 고속·모션블러 대응 학습 + 빠른 트리거 타이밍
정확도 | 모형 딸기 539 장 학습 | 데이터 추가·클래스 밸런싱 + 실물 딸기 대량 테스트로 정량 검증
확장 | 3 종 분류 | 신선도 등급 세분화, 완전 무선화, 통계 대시보드

### 7.2 결론

본 프로젝트는 이질적인 임베디드 보드 세 개를 인식·제어·구동으로 분담·통합하여, AI

신선도 판별과 물리적 분류가 결합된 완결형 자동 선별 라인을 구현하였다. 공개 데이터가

없는 문제는 직접 데이터셋 구축으로, 보드 전용 NPU 버그는 라벨 shift 로, 실환경 오검출은

다단계 제어 로직으로 각각 해결하며 "학습된 모델이 실제 기구에서 신뢰성 있게

동작하기까지"의 전 과정을 경험하였다는 점에서 의의가 있다. 데이터와 속도, 확장성

측면의 과제를 보완한다면 실용적인 농산물 선별 자동화로 확장할 수 있으며, 궁극적으로

스마트 팩토리 시스템으로 발전시킬 수 있을 것으로 기대된다.

## 8. 사용 도구 및 참고자료

구분 | 도구 / 자료
교육과정 | 텔레칩스 팹리스 실무교육과정 (D01–D10) — TOPST 보드 환경, NPU 워크플로, GPIO·CAN·I2C
AI 학습 | YOLOv8 (Ultralytics), PyTorch, Google Colab, LabelImg
NPU 배포 | tc-nn-toolkit / Enlight SDK (ONNX - INT8 양자화 - 컴파일), tcnnapp
임베디드 | Yocto Linux, FreeRTOS, WSL, FWDN(플래싱)
3D 모델링 | Python 파라메트릭 모델링 (STEP/STL), Bambu Studio (X1-Carbon)

## 9. 멘토링 피드백

주요 평가. 현장 문제를 정의하고 후처리 보정으로 해결한 과정, 그리고 AI 의 한계를

비전·제어 알고리즘과 조합해 보완한 복합 시스템 설계 능력을 높이 평가받았으며, 데모도

성공적으로 시연되었다.

기술적 개선 제안.

### 1. 객체 추적(Object Tracking) — 딸기마다 고유 ID 를 부여해 추적하면 중복 검출을

방지할 수 있다(하나의 ID 는 한 번만 처리).

2. 2-Stage 모델(Detection+Classification) — YOLO 로 위치만 빠르게 찾아 크롭한 뒤 경량

분류 모델로 상태를 추론하여 속도와 분류 정확도를 함께 높인다.

현장 적용 인사이트. AI 는 환경 변화에 취약하므로, 현장 맞춤형 재학습과 복수 AI 모델

조합, 전통 비전·제어 알고리즘과의 융합이 필요하며, 본 프로젝트가 그 방향성을 잘

잡았다는 평을 받았다.

## 부록 A. 핵심 변환 명령어 (Converter · Quantizer · Compiler)

# Converter (.onnx -> .enlight, FP32)

python ./EnlightSDK/converter.py best_extracted.onnx \
--type obj --add-detection-post-process best.bin \ --dataset Custom --dataset-root <calibration_images> \ --enable-track --mean 0 0 0 --std 1 1 1 \
--num-class 4 --yolo-version v8 --enable-letterbox \ --dfl-reg-max 16 --output-order cl \
--logistic sigmoid --no-background | # class 0 버그 대응

# Quantizer (FP32 -> INT8)

python ./EnlightSDK/quantizer.py best.enlight --output best_quantized.enlight --m-std-4 7

# Compiler (NPU 명령어 + 후처리 생성)

python ./EnlightSDK/compiler.py best_quantized.enlight --th-iou 0.5 --th-conf 0.5

## 부록 B. 실행 런북 (운영 절차)

B.1 사전 준비

# AI-G IP 설정 (영구화 안 된 경우)

ifconfig eth0 192.168.10.100 netmask 255.255.255.0 up
# D3-G IP 고정 (NetworkManager 가 static IP 를 지우므로 managed 해제 후 설정) sudo nmcli device set eth0 managed no

sudo ifconfig eth0 192.168.10.101 netmask 255.255.255.0 up
ping 192.168.10.101 -c 2 | # AI-G 에서 연결 확인
ls /dev/video* | # 카메라 확인

B.2 실행 / 단독 테스트

# 1) D3-G — 제어 시작 (TCP 대기)

cd /home/topst && python3 fruit_controller.py # 2) AI-G — 인식 시작
sh /home/root/ai_result_sender.sh

# TCP 단독 테스트 (스크립트 없이 AI-G 에서 수동 전송)

echo "CLASS:0,CONF:85,X:0.50,Y:0.50,W:0.30,H:0.30" | nc 192.168.10.101 5000

## 부록 C. 시스템 통합 디버깅 히스토리

프로젝트 진행 중 마주친 주요 이슈와 해결 과정이다. 다수가 실환경 특유의 문제(통신 IP

풀림, NPU 노이즈, I2C stuck 등)로, 소프트웨어와 하드웨어를 오가며 격리·해결하였다.

# | 증상 | 원인 - 해결

1 | IPC 전송해도 R5 무반응 | R5 log on 미입력 (단, 콜드사이클 재검증 결과 현재 불필요)
2 | 서보 무반응 / 컨베이어 오동작 | 전송 형식 오류 - 서보 byte0=각도, 컨베이어 (action,speed)
3 | LED 제어 안 됨 | 3 바이트 전송 - 2 바이트(id, on/off)로 변경
4 | IPC sndrecv 크래시 | TypeError(BufferedWriter) - snd 모드만 사용
5 | python3: not found (AI-G) | Yocto 에 Python 없음 - sh + awk + nc 로 구현
6 | No route to host / ping loss | eth0 IP 풀림 + NetworkManager 가 static IP flush - nmcli managed no + ifconfig 고정
7 | 트리거 방식 진화 | 쿨다운 - 엣지 트리거 - 2D 박스 + gap 으로 발전 (과다 카운트 해결)
8 | NPU 유령 검출로 헛트리거 | 좌표 점프·구석 멈춘 유령 - 박스 + 디바운스(3 프레임)로 완화 (근본은 모델 품질)
9 | 밀려서 출력 / 빈 벨트에 모터 돔 | 서보 blocking 으로 동작 큐 백로그 - non-blocking(바쁘면 건너뜀)으로 변경
10 | 신선 딸기에 모터가 돔 | 모델이 그 프레임을 썩음/덜익음으로 오분류 -MIN_CONFIDENCE, CONFIRM 상향 (근본은 모델)
11 | 무선 run 에서 모터만 안 돎 | 점퍼 접합부 절연테이프로 접촉 불량 (LED·CAN 정상으로 격리) - 테이프 제거
12 | run 끝나도 LCD 통계 안 뜸 | update_lcd 가 종료 경로에서만 호출 - main() finally 에도 추가 (Ctrl+C 포함 표시)

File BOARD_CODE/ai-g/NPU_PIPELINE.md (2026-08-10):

# AI-G board pipeline - deploying the strawberry model on the NPU

Written by Kang Yohan, who handled training and NPU deployment, and shared with the
control and integration side of the team. It records the whole path from dataset to
on-board inference, and it is the reference for how detection classes reach the
controller.

---

## 0. The whole flow

```
[train]    PyTorch / Ultralytics YOLOv8n
             build the dataset -> train on Colab -> best.pt
                 |
[convert]  tc-nn-toolkit (WSL, EnlightSDK)
             1) ONNX export      best.pt  -> best.onnx
             2) ONNX extract     best.onnx -> best_extracted.onnx (post-process split off)
             3) default box gen  best.onnx -> best.bin (grid information)
             4) converter        -> best.enlight (FP32)
             5) quantizer        -> best_quantized.enlight (INT8)
             6) compiler         -> net.h, post_process.c, npu_cmd.bin, quantized_network.bin
                 |
[build]    ARM aarch64 cross compile
             net.so
                 |
[deploy]   scp to the board at 192.168.0.100
             /usr/share/strawberry_shifted_v2_quantized/
                 |
[run]      tcnnapp -> camera input -> NPU inference -> detections on stdout
```

The backbone of the work is the vendor course material: the same command sequence,
with the strawberry model substituted for the example one.

---

## 1. Where this came from

The Telechips course walks up through the NPU workflow one step at a time.

| Example | Model | What it teaches | How it was used |
|---|---|---|---|
| Day 6, 02 | LeNet-5, classification | the basic convert / quantize / compile flow | learning the command structure |
| Day 6, 06 | YOLOv8s, detection | converting a detection model and splitting off post-processing | the main reference; our model is the same family |
| Day 7, 02 | UFLD, lane detection | editing the tc-nn-app source, custom post-processing | reference for visualisation and labels |

The strawberry YOLOv8n follows the day 6 example almost exactly. The `yolov8s_convert`
function was used as written, changing only the input filenames and the class count.

```
course YOLOv8s              our model
yolov8s_extracted.onnx  ->  best_extracted.onnx
yolov8s.bin             ->  best.bin
--num-class 80 (COCO)   ->  --num-class N
everything else         ->  unchanged
```

---

## 2. Dataset and training

### Dataset

Model strawberries in three states were photographed from a range of angles and
distances and labelled by hand in LabelImg. The final set is 539 images, 475 for
training and 64 for validation, with extra coverage for the rotten class. The split
is by shooting session rather than by image, so no scene appears on both sides of it.

### Training

```python
from ultralytics import YOLO

model = YOLO("yolov8n.pt")     # nano; the board has 2 GB
model.train(
    data="data.yaml",
    epochs=800,
    imgsz=640,                 # this value has to stay consistent all the way through
    batch=16,
)
```

Output: `best.pt`, mAP50 around 0.99.

The 640 image size carries through ONNX export, the converter and on-board inference.
If any one of those disagrees, the box coordinates come out wrong.

---

## 3. ONNX export

```bash
cd ~/Work/tc-nn-toolkit
source venv/bin/activate     # torch 1.12.0+cpu, ultralytics 8.4.46
```

The first attempt used `opset=12, simplify=True`, and that turned out to matter:

```python
from ultralytics import YOLO
model = YOLO("best.pt")

# first attempt
model.export(format="onnx", imgsz=640, opset=12, simplify=True)
# simplify=True folds the graph and erases the cv2/cv3 node names,
# which the extract step needs to find its outputs

# what actually works, matching the course example
model.export(format="onnx", opset=10)
```

| Option | Value | Why |
|---|---|---|
| `opset` | 10 | 12 and above emit operators the toolkit does not support |
| `simplify` | left off | turning it on removes the node names, making extract impossible |

The export reports:

```
input  (1, 3, 640, 640)
output (1, 6, 8400)
```

which reads as batch 1, then 4 box coordinates plus 2 class scores, then the anchor
count 80x80 + 40x40 + 20x20. The class count is visible in the second dimension, so
this line alone confirms how many classes the model has.

Even with `simplify` off the node *names* get rewritten, but the *weight* names such
as `model.22.cv2.0.2.weight` survive. That is what the next step keys off.

---

## 4. Extracting the raw head outputs

A stock YOLOv8 ONNX has DFL decode, sigmoid and NMS built into the end of the graph.
The NPU is good at convolution, batch norm and activations, and bad at the DFL
softmax, at NMS and at sigmoid. So the network runs on the NPU only as far as the raw
convolution outputs of the head, and the rest happens on the Cortex-A53.

The detect head has six outputs, one classification and one regression tensor per
stride:

```
cv3.0.2  cls, stride 8   [1, nc, 80, 80]
cv2.0.2  reg, stride 8   [1, 64, 80, 80]     64 = reg_max(16) x 4
cv3.1.2  cls, stride 16  [1, nc, 40, 40]
cv2.1.2  reg, stride 16  [1, 64, 40, 40]
cv3.2.2  cls, stride 32  [1, nc, 20, 20]
cv2.2.2  reg, stride 32  [1, 64, 20, 20]
```

Since the node names are gone, they are found through the weights:

```python
import onnx
m = onnx.load('best.onnx')

target_weights = {
    "cls_s8":  "model.22.cv3.0.2.weight",   # shape [nc, 64, 1, 1]
    "reg_s8":  "model.22.cv2.0.2.weight",   # shape [64, 64, 1, 1]
    "cls_s16": "model.22.cv3.1.2.weight",
    "reg_s16": "model.22.cv2.1.2.weight",
    "cls_s32": "model.22.cv3.2.2.weight",
    "reg_s32": "model.22.cv2.2.2.weight",
}
# resolves to onnx::Reshape_314, _328, _342, _357, _371, _385
```

The first dimension of each `cv3.*.weight` should equal the class count. If it does,
training produced what was intended.

```python
import onnx

OUTPUT_LAYER = [
    "onnx::Reshape_357",  # cv3.0.2, cls stride 8
    "onnx::Reshape_314",  # cv2.0.2, reg stride 8
    "onnx::Reshape_371",  # cv3.1.2, cls stride 16
    "onnx::Reshape_328",  # cv2.1.2, reg stride 16
    "onnx::Reshape_385",  # cv3.2.2, cls stride 32
    "onnx::Reshape_342",  # cv2.2.2, reg stride 32
]
onnx.utils.extract_model(
    "best.onnx", "best_extracted.onnx",
    ["images"],
    OUTPUT_LAYER,
)
```

Node count drops from 231 to 207, removing the 24 post-processing nodes. The course
provides `extract_yolo_onnx.sh` for this, which calls the same function.

---

## 5. Default boxes

The grid and anchor information goes into a separate binary so the on-board
post-processing can map a pixel position back to its grid cell.

```bash
python tools/gen_default_box_tools/default_box_generator.py \
    input_networks/strawberry/best.onnx \
    --output input_networks/strawberry/best.bin \
    --version v8 \
    --grid-layer-name onnx::Reshape_314 onnx::Reshape_328 onnx::Reshape_342
```

The three named layers are the regression outputs at strides 8, 16 and 32.

The generated file broke the converter:

```
generated best.bin      GENBIN_V1, 134528 bytes
course yolov8s.bin      FENBIN_V1,  67328 bytes

Exception: [Error] YOLO grid file is invalid.
           Network output and grid shape do not match
```

Within the same toolkit, `default_box_generator` writes the newer format while
`converter.py` still expects the older one. The fix was to reuse the course file:

```bash
cp input_networks/Education/ai_model/yolov8s.bin \
   input_networks/strawberry/best.bin
```

That is legitimate because the grid does not depend on backbone size. The s, m and n
variants all use strides 8/16/32, `reg_max` 16 and a 640x640 input, so the grid
mapping is identical, and the class count comes from the converter's `--num-class`
rather than from this file. With a later toolkit version the final model generated a
correct 67328-byte `best_shifted_v2.bin`.

---

## 6. Converter, to FP32 enlight

Quantisation needs activation statistics, which means calibration images. They have
to be the project's own training images for the accuracy to hold.

```bash
cp ~/Work/strawberry_dataset/train/images/*.jpg my_dataset_path/
```

```bash
python ./EnlightSDK/converter.py \
    input_networks/strawberry/best_extracted.onnx \
    --type obj \
    --add-detection-post-process input_networks/strawberry/best.bin \
    --dataset Custom \
    --dataset-root my_dataset_path \
    --output output_networks/best.enlight \
    --enable-track \
    --mean 0 0 0 \
    --std 1 1 1 \
    --num-class 4 \
    --yolo-version v8 \
    --enable-letterbox \
    --dfl-reg-max 16 \
    --output-order cl \
    --logistic sigmoid \
    --no-background
```

| Option | Meaning | Why |
|---|---|---|
| `--type obj` | object detection | YOLO is a detection task |
| `--add-detection-post-process` | inject the grid | needed by the on-board post-processing |
| `--dataset Custom --dataset-root` | calibration images | source of the quantisation statistics |
| `--enable-track` | collect activation statistics | the basis of INT8 quantisation |
| `--mean 0 0 0 --std 1 1 1` | no normalisation | YOLOv8 only scales to 0-1; it does not use ImageNet statistics |
| `--num-class 4` | class count | four after the label shift described below |
| `--yolo-version v8` | v8 detect head | selects how the head is handled |
| `--enable-letterbox` | aspect-preserving resize | objects are not squashed |
| `--dfl-reg-max 16` | DFL bin count | must match training |
| `--output-order cl` | classification first | the memory order the NPU expects |

Result:

```
Number of compatible layers   : 216
Number of incompatible layers :   0
Total number of layers        : 216

output_networks/best.enlight, about 12 MB
```

Zero incompatible layers means the whole network maps onto the NPU, so nothing like
the unsupported reshape in the lane-detection example applies here.

---

## 7. The class 0 problem and the label shift

This is the most important finding in the project, and it is what determines the
class mapping the controller sees.

On the PC simulator every class is detected. On the board, class index 0 never
appears:

```
enlight_sim (INT8)          board (tcnnapp)
  class 0  ok, 93%            class 0  never appears
  class 1  ok, 95%            class 1  ok
  class 2  ok, 94%            class 2  ok
```

It was isolated as follows. Changing converter options improved other things but not
this. Running the same quantised model through `enlight_sim` on the PC detected class
0 correctly, so the file is fine. The MD5 of `net.so` matched on both sides, so the
transfer is fine. Running the board with `-g log` to print raw class indices showed
class 0 never being emitted at all.

The conclusion is that the tcnnapp post-processing treats class index 0 as
background and drops it.

The workaround is to shift every training label up by one and leave class 0 empty:

```bash
for f in train/labels/*.txt valid/labels/*.txt; do
    awk '{$1=$1+1; print}' "$f" > "$f.tmp" && mv "$f.tmp" "$f"
done
```

```
before, nc = 3               after, nc = 4
  0 = fresh   (never seen)     0 = dummy, unused
  1 = unripe                   1 = fresh
  2 = rotten                   2 = unripe
                               3 = rotten
```

Every real class now sits at index 1 or above. The model was retrained and converted
with `--num-class 4`.

### What the controller receives

tcnnapp shifts the index by one again on output, so the mapping from the wire format
to the project classes is:

```
tcnnapp     meaning     project class     action
 class 2     fresh       0 fresh          plate stays level, fruit passes
 class 3     unripe      2 unripe         plate tilts right
 class 4     rotten      1 rotten         plate tilts left
 anything else           dropped          not transmitted
```

This is why `ai_result_sender.sh` parses only classes 2, 3 and 4 and skips the rest.

---

## 8. Quantizer, FP32 to INT8

```bash
python ./EnlightSDK/quantizer.py \
    output_networks/best.enlight \
    --output output_networks/best_quantized.enlight \
    --m-std-4 7
```

It loads the FP32 weights together with the activation statistics the converter
gathered, computes a per-layer scale and zero point, converts the weights to INT8 at
roughly a quarter of the size, and writes the result:

```
quantized_value = round(real_value / scale) + zero_point
```

`--m-std-4` sets the activation clipping range. The default of 5 lost too much of the
difference between classes once compressed to INT8, so it was raised to 7.

Verify with `enlight_sim.py` on the PC before flashing the board. One to three
percent of accuracy lost to quantisation is normal; ten percent or more points at
something else, usually too little calibration data.

---

## 9. Compiler

```bash
python ./EnlightSDK/compiler.py \
    output_networks/best_quantized.enlight \
    --th-iou 0.5 \
    --th-conf 0.5
```

Outputs:

```
net.h                    network structure header
post_process.c           model-specific post-processing (DFL decode, sigmoid, NMS)
npu_cmd.bin              NPU instruction sequence
quantized_network.bin    INT8 weights
```

`--th-conf` discards detections below 0.5 confidence and `--th-iou` sets the NMS
overlap threshold. The compiler notification should show cv3 mapped to the confidence
layers and cv2 to the location layers.

---

## 10. Building net.so

```bash
cd build_network/
# symlink network.h and post_process.c, then
make
```

Toolchain: `gcc-arm-9.2-2019.12-x86_64-aarch64-none-linux-gnu`.

tcnnapp itself stays as it is; swapping `net.so` is enough to change models. The
lane-detection example needed a full bitbake rebuild because of its custom
post-processing, but a standard YOLOv8 head does not.

---

## 11. Deployment

```bash
scp net.so npu_cmd.bin quantized_network.bin \
    root@192.168.0.100:/usr/share/strawberry_shifted_v2_quantized/

md5sum net.so npu_cmd.bin quantized_network.bin
```

The three files in `/usr/share/strawberry_shifted_v2_quantized/` are one set: the
post-processing logic, the NPU instructions and the INT8 weights.

---

## 12. Running inference

```bash
tcnnapp \
    -n /usr/share/strawberry_shifted_v2_quantized/ \
    -i camera \
    -p /dev/video2 \
    -o display \
    -w 1280 -h 720 \
    -W 800 -H 480 \
    -g log
```

| Option | Meaning |
|---|---|
| `-n` | model directory, where the compiler output lives |
| `-i camera` | input mode |
| `-p /dev/video2` | V4L2 device |
| `-o display` | output over HDMI |
| `-w -h` | input resolution |
| `-W -H` | output resolution |
| `-g log` | debug log, which is where raw class indices appear |

In normal operation `ai_result_sender.sh` parses this output with awk and sends it to
the D3-G board over TCP. A detection line looks like:

```
x1 y1 x2 y2 = 321.5 277.5 509.9 642.3 class: 3 score: 82.89
```

The script takes the class and the box centre and sends `CLASS,CONF,X,Y`.

---

## 13. Things that went wrong

| Symptom | Cause and fix |
|---|---|
| extract cannot find the cv2/cv3 nodes | `opset=12` with `simplify=True` erased the names; use opset 10 with simplify off |
| converter reports "YOLO grid file is invalid" | the generated `.bin` is a newer format than the converter accepts; reuse the course `yolov8s.bin` |
| class 0 never detected on the board | tcnnapp treats index 0 as background; shift all labels up by one and leave class 0 empty |
| classes poorly separated after quantisation | raise `--m-std-4` from 5 to 7 |
| board misclassifies while the PC is correct | `--logistic` and `--no-background` were unset; specify them explicitly |

---

## 14. The full sequence

```bash
# ONNX export
python3 -c "from ultralytics import YOLO; YOLO('best.pt').export(format='onnx', opset=10)"

# extract the six head outputs
python3 extract_strawberry.py

# default boxes, or reuse the course file
cp input_networks/Education/ai_model/yolov8s.bin input_networks/strawberry/best.bin

# converter
python ./EnlightSDK/converter.py \
    input_networks/strawberry/best_extracted.onnx \
    --type obj --add-detection-post-process input_networks/strawberry/best.bin \
    --dataset Custom --dataset-root my_dataset_path \
    --output output_networks/best.enlight \
    --enable-track --mean 0 0 0 --std 1 1 1 \
    --num-class 4 --yolo-version v8 --enable-letterbox \
    --dfl-reg-max 16 --output-order cl --logistic sigmoid --no-background

# quantizer
python ./EnlightSDK/quantizer.py \
    output_networks/best.enlight \
    --output output_networks/best_quantized.enlight --m-std-4 7

# compiler
python ./EnlightSDK/compiler.py \
    output_networks/best_quantized.enlight --th-iou 0.5 --th-conf 0.5

# build the post-processing library
cd build_network && make

# deploy
scp net.so npu_cmd.bin quantized_network.bin \
    root@192.168.0.100:/usr/share/strawberry_shifted_v2_quantized/

# run
tcnnapp -n /usr/share/strawberry_shifted_v2_quantized/ \
    -i camera -p /dev/video2 -o display -w 1280 -h 720 -W 800 -H 480 -g log
```

---

## 15. What the control side needs to know

1. The class indices are shifted by one because of the NPU behaviour above. tcnnapp
   emits class 2 for fresh, 3 for unripe and 4 for rotten, and `ai_result_sender.sh`
   maps those onto the project classes 0, 1 and 2 before transmitting. The controller
   uses the received value as it stands.
2. The model lives in `/usr/share/strawberry_shifted_v2_quantized/` as a set of three
   files. Changing models means replacing all three.
3. Retraining and reconverting follows the sequence in section 14 unchanged apart
   from `--num-class`, but the labels must stay shifted so that class 0 is empty.

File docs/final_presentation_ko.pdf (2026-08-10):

# 고급프로젝트

# 최종 발표

1조

### 강요한 | 채지훈

딸기 자동 분류 시스템

## 구현 방법

01

02

03

04

05

## 결과물

## 집중한 부분

## 발전 가능성

06 | 사용 도구 및 참고자료

## 프로젝트 아이디어

목차

# 1. 프로젝트 아이디어

•딸기 자동 분류 시스템- "AI가 신선도를 확인하고, 회전판이 자동으로 분류한다”


- 착안: 텔레칩스 자율주행 차량 키트의 기본 뼈대 — 인식(AI-G) → 제어·통신(D3-G) → 구동(VCP-G) — 구조에 착안
- 기능: 사람 없이 AI 모델을 통한 딸기 신선도 판별 + 물리적 분류 → 농산물 선별 자동화

# 2. 구현 방법

## - 시스템 구성: 역할이 다른 3개 보드가 인식 → 제어 → 구동을 나눠 맡아 하나로 연결

- 역할 분담: 인식(AI-G) · 제어·통신(D3-G) · 구동(VCP-G) — 한 보드가 다 하지 않고 나눠 처리 후 통합
- 서로 다른 종류 3보드: NPU(인식) · Linux+RTOS 듀얼코어(제어) · MCU(구동) — 칩·OS·언어가 모두 달라 통합이 핵심 난이도
- 통신 3단: 이더넷(TCP) → IPC(공유메모리) → CAN — 구간마다 다른 방식을 맞물려 연결

# AI-G

카메라 + NPU

D3-G

A72 + R5

# VCP-G

서보·LED ·LCD

이더넷(TCP) | CAN

IPC

## 2. 구현 방법 – AI 학습·NPU 배포


- 데이터셋: 딸기 3종(신선 · 썩음 · 덜익음) 직접 촬영 + 라벨링
- 모델 학습: 경량 모델 YOLOv8n으로 3종 분류 학습
- 양자화·배포: NPU에서 돌도록 INT8 양자화 후 보드 탑재

# 2. 구현 방법 – 제어부


- HW: VCP가 구동하는 부품 = 회전판 서보(SG90) · LED 3색 · LCD

• 알고리즘: "딸기 1개 = 정확히 1회 동작“; 디바운스 (3프레임); 신뢰도; 비차단 서보; Gap

- 전달: D3-G 판단 → IPC → R5 → CAN(0x111, 목표 각도) → VCP가 그 각도로 서보 구동

서보

- 동작: 위치제어 SG90 — 신선 90°(통과) / 썩음 50°(좌) / 덜익음 130°(우),

1.3초 유지 후 90° 복귀

LED — 분류 결과 즉시 표시

- 3색: 빨강=썩음 / 노랑=덜익음 / 초록=신선 — 감지 즉시 점등 → 1초 후 자동 소등
- 멀티 점등: 색마다 독립 타이머 → 여러 색 동시 가능,


같은 색 재감지는 타이머만 갱신(중복 전송 X)
- 논블로킹: 백그라운드로 보내 모터(서보) 타이밍을 절대 안 막음 (모터 우선)

# LCD — 누적 통계

- 전체/신선/썩음/덜익음 누적 → 분류 종료(30초 무감지)나 정지 시 표시

# 2. 구현 방법 – 제어부


# 2. 구현 방법 – 시스템 통합


- 전 구간 실동작: 카메라 인식 → 판단 → 회전판·LED·LCD까지 세 보드가 끊김 없이 하나로 (구성을 실제로 통합)
- 무선 한 줄 운영: PC에서 D3-G에 SSH 명령 한 줄 → AI-G까지 자동 기동, 끝나면 자동 종료
- 현장 튜닝(코드화): 박스·각도·시간을 코드 상수로 → 모델 거동 보며 재플래싱 없이 즉시 조정

## 3. 결과물 – 3D 모델링


- 컨트롤 타워: 보드 3개(AI-G·D3-G·VCP)를 3층으로 적층 수납 — 깔끔한 통합 하우징
- 회전판: SG90에 직결 — 좌·우·수평으로 기울어 종류별 배출(분류 게이트)
- 지지대: 회전판을 지면과 30° 경사로 받쳐 → 신선 딸기가 굴러 통과

# 3. 결과물 – 전체 시스템


- 물리 구성: 카메라(AI-G) → 컨베이어(외부 구동) → 끝단 회전판(서보)+30° 경사 지지대 + 상태 LED 3색·LCD 통계

# 3. 결과물 – 전체 시스템


- 작동 흐름: 전원 ON → 딸기 흘림 → 감지 구간 도달 시 회전판이 좌·우·수평으로 분류 → LED·LCD로 결과 표시

## 4. 집중한 부분 – AI 학습


- 학습 데이터 직접 제작 (539장): 딸기 신선도용 공개 데이터셋이 없어 → 딸기 모형을 다양한 거리·각도로 직접 촬영·라벨링
- 정확도 끌어올림 (mAP50 0.99): 반복 학습(약 6회)·튜닝으로 분류 정확도 확보
- 증강: mosaic·mixup 증강으로 실환경(거리·각도·움직임) 대응
- NPU class 0 버그 우회: PC에선 정상인데 보드에선 class 0 누락 → 라벨 +1 shift로 해결

## 4. 집중한 부분 – 문제발생!!

## ① 문제: 처음엔 Y좌표만으로 판단해서 딸기가 너무 빨리·예민하게 감지됨

## ② 문제: 덜익음이 학습량이 많아 다른 클래스보다 너무 잘 검출됨

## ③ 문제: 신선 딸기가 가끔 썩음/덜익음으로 오검출됨

## → "감지하면 바로 동작"으로는 신뢰성 부족, 실제 환경에서 마주한 문제

# → 제어 로직으로 보정

# 4. 집중한 부분 – AI 결과 강화(해결)


- ① (너무 빨리·예민하게 감지) → X·Y 좌표를 모두 쓰는 "감지 박스" → 회전판 자리에 왔을 때만 트리거
- ② (덜익음 과검출) → 덜익음만 감지 박스를 작게 → 트리거를 늦춰 다른 클래스와 타이밍 맞춤
- ③ (신선 오분류) → 신선이 한 번이라도 잡히면 신선으로 분류(신선 우선) — 반대 오검출은 없으므로

덜 익은 감지 박스

기존 감지 박스

# 4. 집중한 부분 – 제어&통합

# 작동 로직

감지 박스: 회전판 앞 구역(X·Y)에 온 딸기만 — 먼 딸기·유령 제외


디바운스: 연속 3프레임 잡혀야 진짜 — 반짝 튀는 신호 무시 gap 재무장: 사라졌다 다시 와야 새 딸기 — 같은 딸기 중복 방지 비차단 서보: 도는 중 트리거는 건너뜀 — 밀려 헛도는 것 방지

# 통합/운영

튜닝의 코드화: 박스·각도·시간을 코드 상수로 → 모델 동작


보며 재플래싱 없이 즉시 조정


# 5. 발전 가능성

딸기가 하나씩 간격을 두고 이동 | 여러 개 동시·밀집 감지에도 정확 분류
| (AI 다중 객체 인식 향상 + 분류 제어 시스템 정교화)

## 처리량

컨베이어 위 딸기 이동이 느림 | 빠르게 들어오는 객체도 정확 인식
| (고속·모션블러 대응 AI 학습 + 빠른 트리거 타이밍)

속도

모형 딸기 데이터 539장 학습 | 학습 데이터 추가·클래스 밸런싱
| → 오분류·보정 의존도 감소 + 실물 딸기 대량
| 테스트로 정량 검증

## 정확도

딸기 클래스 3종 외 다른 클래스 존재X
(신선/덜익은/썩은)

분류 종류·신선도 등급 세분화 / 완전 무선화 / 시작·종료 버튼 / 통계 대시보드

## 확장/실용화

# 6. 사용 도구 및 참고자료

- 교육과정: 텔레칩스 팹리스 실무교육과정 (D01–D10) — TOPST 보드(AI-G·D3-G·VCP) 환경, NPU 워크플로,

GPIO·CAN·I2C·PDM, AI-G YOLO 적용

- AI 학습: YOLOv8 (Ultralytics) · PyTorch · Google Colab(학습) · LabelImg(라벨링)
- NPU 배포: tc-nn-toolkit / Enlight SDK (ONNX → INT8 양자화 → 컴파일) · tcnnapp(NPU 추론)
- 임베디드: Yocto Linux · FreeRTOS · WSL · FWDN(플래싱)
- 3D 모델링·출력: Python 파라메트릭 모델링(STEP/STL) · Bambu Studio(X1-Carbon)

# 5. 고민했던 부분(그냥 뺄까 생각중 별로 안중요해서)

- [AI 배포] 보드에서만 class 0 누락 (PC는 정상) → 체계적 진단(PC sim·MD5·raw log) → NPU가 0번을 배경으로 무시 확인 → 라벨 +1 shift로 우회
- [제어] 회전판 1개 + 노이즈로 모터가 헛돌고 밀림 → 비차단 서보(동작 중 스킵) + 박스·디바운스로 "1개=1회"
- [제어] LCD가 백라이트만 켜지고 글자 안 뜸 → I2C 불가능한 핀에 배선된 것을 진단 → 정식 I2C 핀으로 이설
- [통합] "제어가 다 무시된다"를 'log on 필수'로 알았으나 → 콜드부팅 재검증으로 불필요 확정(매 전원 수동단계 제거)

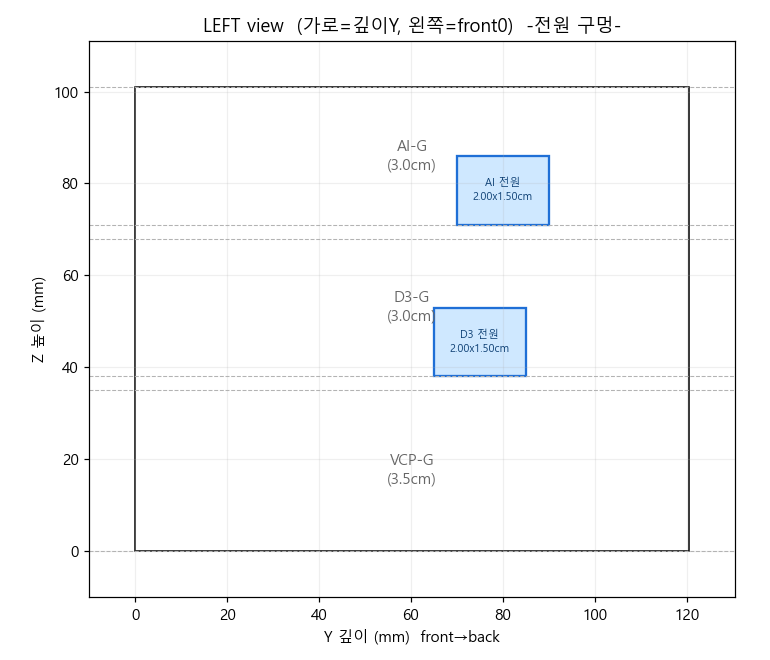
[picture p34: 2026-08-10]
3d-model/preview/preview_left.png

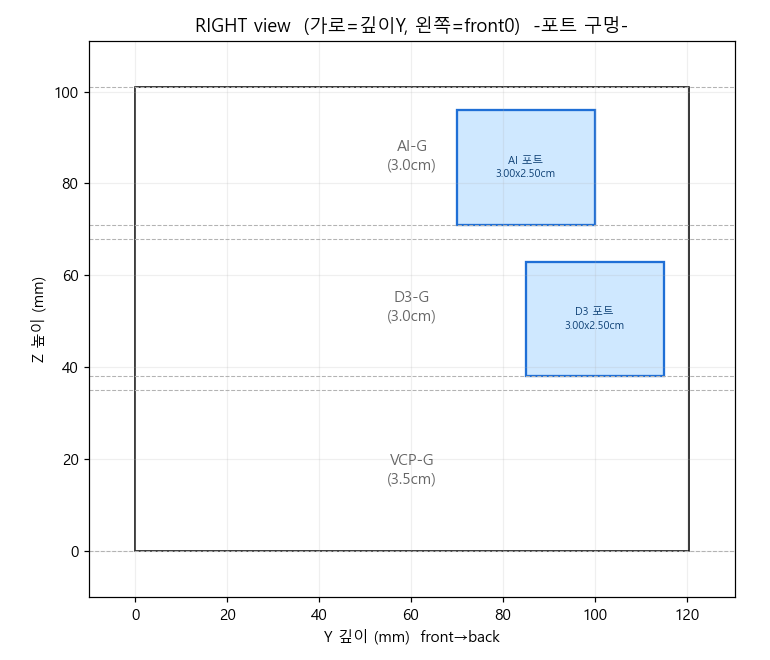
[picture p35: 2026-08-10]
3d-model/preview/preview_right.png

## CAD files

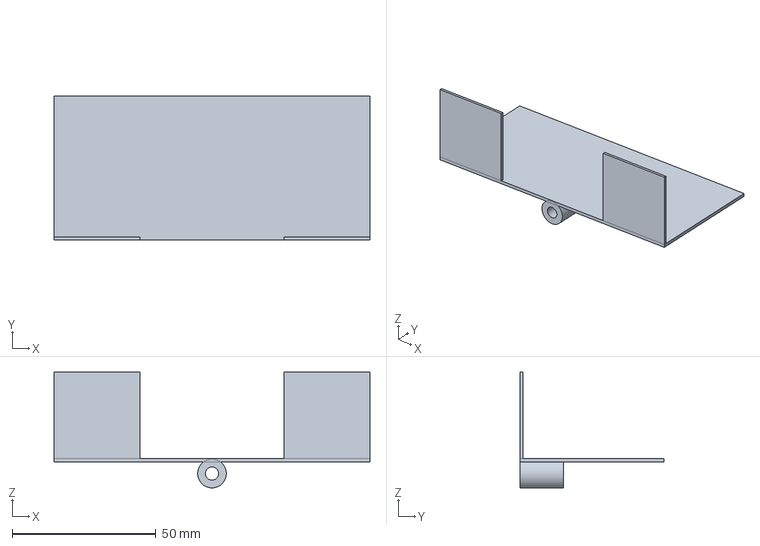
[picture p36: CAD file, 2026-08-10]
3d-model/model_file/rotation_plate.step
110.0 x 50.0 x 40.3 mm

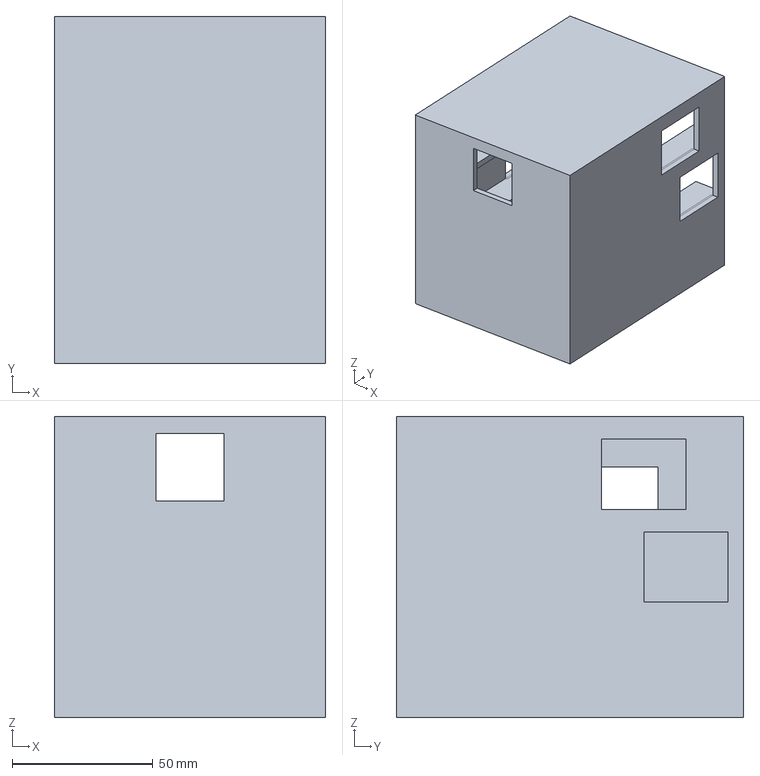
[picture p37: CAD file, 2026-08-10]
3d-model/model_file/strawberry_box.step
96.5 x 123.5 x 107.0 mm

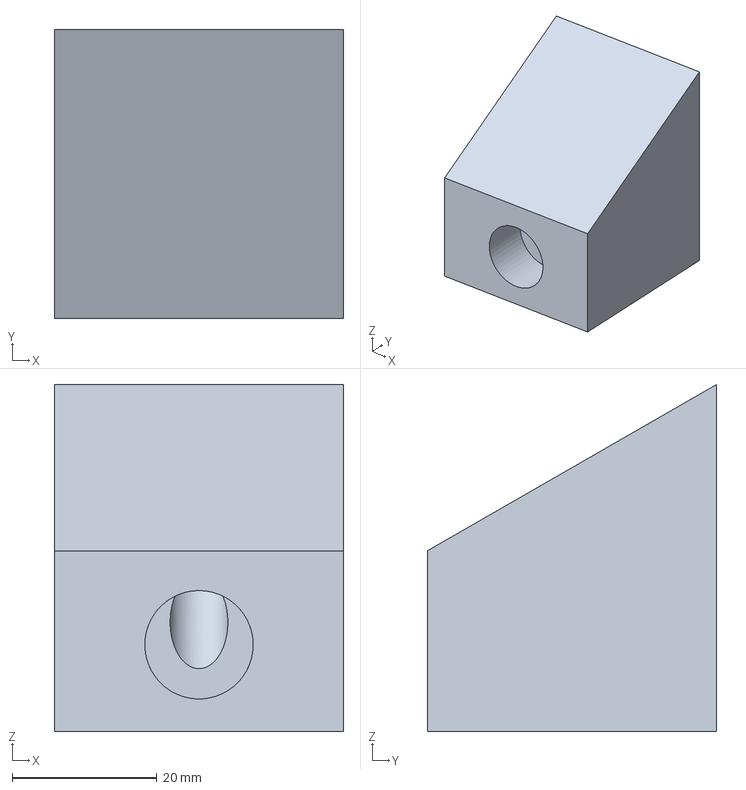
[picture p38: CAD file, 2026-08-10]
3d-model/model_file/support.step
40.0 x 40.0 x 48.0 mm

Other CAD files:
3d-model/model_file/rotation_plate.stl
3d-model/model_file/strawberry_box.stl
3d-model/model_file/support.stl

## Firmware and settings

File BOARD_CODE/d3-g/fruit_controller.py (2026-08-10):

#!/usr/bin/env python3
"""
Strawberry sorting - control code for the D3-G A72 core
AI-G over TCP -> classify -> position trigger -> IPC -> R5 -> CAN -> VCP-G (servo, LED, LCD)

Sorting is done by angle on a single SG90 servo driving the tilt plate:
  - fresh  : stays at the default 90 degrees (level), so the fruit passes through
  - rotten : tilts 40 degrees left, holds briefly, then returns to level
  - unripe : tilts 40 degrees right, holds briefly, then returns to level

Assumptions:
  - the servo is position controlled; byte 0 of the CAN frame carries the target angle
  - the conveyor runs from its own controller, so this code does not touch it
  - the plate acts when the reported coordinates fall inside the trigger box

Values that get tuned on the rig:
  1. the tilt angles
  2. the trigger box, measured so it lands exactly on the plate position

Usage: sudo python3 fruit_controller.py
IPC_Example.py from the board SDK is invoked as a subprocess in send mode.
"""

import socket
import time
import threading
import subprocess
import os

# ============================================================
# network and CAN identifiers
# ============================================================
AI_G_PORT          = 5000     # TCP port the AI board connects to
SERVO_CAN_ID       = 0x111    # tilt plate servo
CAN_ID_LED_CONTROL = 0x114    # LED control
CAN_ID_LCD_STATS   = 0x116    # LCD statistics
# The second servo and the conveyor channel are no longer used; both are external.

# ============================================================
# Orchestration: this board starts and stops recognition on the AI board over SSH,
#   so the whole run is a single command: fix the local IP, start recognition,
#   act on the results, and shut everything down after 30 seconds of silence.
#   One-time setup: static IP on the AI board, sshd running, and a passwordless key.
# ============================================================
ORCHESTRATE   = True                  # drive the AI board over SSH automatically
SETUP_D3G_NET = True                  # pin the local ethernet address at start-up
AIG_USER      = "root"                # AI board login
AIG_IP        = "192.168.10.100"      # AI board ethernet address
D3G_ETH_IP    = "192.168.10.101"      # D3-G eth0 IP
AIG_START_CMD = "sh /home/root/ai_result_sender.sh"   # start recognition and streaming
AIG_STOP_CMD  = "pkill -f tcnnapp 2>/dev/null; killall tcnnapp 2>/dev/null; true"  # stop it (busybox safe)

def _ssh_aig(remote_cmd, background=False):
    cmd = ["ssh", "-o", "StrictHostKeyChecking=no", "-o", "BatchMode=yes",
           "-o", "ConnectTimeout=5", f"{AIG_USER}@{AIG_IP}", remote_cmd]
    try:
        if background:
            subprocess.Popen(cmd)
        else:
            subprocess.run(cmd, timeout=10)
    except Exception as e:
        print(f"  [ssh error] {e} - check the key and the network")

def start_aig():
    print(f"[ai] starting recognition on {AIG_USER}@{AIG_IP}")
    _ssh_aig(AIG_START_CMD, background=True)

def stop_aig():
    print("[ai] stopping recognition")
    _ssh_aig(AIG_STOP_CMD, background=False)

def setup_d3g_net():
    """Pin the ethernet address so NetworkManager does not clear it."""
    try:
        subprocess.run(["sudo", "nmcli", "device", "set", "eth0", "managed", "no"], timeout=5)
        subprocess.run(["sudo", "ifconfig", "eth0", D3G_ETH_IP, "netmask", "255.255.255.0", "up"], timeout=5)
        print(f"[net] eth0 fixed at {D3G_ETH_IP}")
    except Exception as e:
        print(f"[net] could not configure eth0, do it by hand: {e}")

# ============================================================
# classes and LED colours
# ============================================================
CLASS_FRESH  = 0              # stays level and passes through
CLASS_ROTTEN = 1             # tilts left
CLASS_UNRIPE = 2             # tilts right
CLASS_NAMES  = {0: "fresh", 1: "rotten", 2: "unripe"}
LED_RED    = 1               # rotten
LED_YELLOW = 2               # unripe
LED_GREEN  = 4               # fresh

# ============================================================
# Tuning constants. Everything adjusted on the rig lives here.
# ============================================================
# --- 1. tilt angles ---
SERVO_DEFAULT_DEG = 90       # level, the resting position
SERVO_LEFT_DEG    = 50       # 40 degrees left, for rotten
SERVO_RIGHT_DEG   = 130      # 40 degrees right, for unripe
SERVO_HOLD_TIME   = 1.3      # seconds held tilted, long enough for the fruit to roll off

# --- 2. trigger box: both the X and the Y range must be satisfied ---
#    The belt runs diagonally across the frame, so fruit at the plate always
#    appears at a particular spot. Boxing that spot rejects fruit further up the
#    belt and phantom detections in the corners. Measure with DEBUG_COORDS.
TRIGGER_Y_LO = 390         # top edge, measured at the plate
TRIGGER_Y_HI = 490         # bottom edge
TRIGGER_X_LO = 230         # left edge; real fruit sits at 230-375, corner ghosts at 118
TRIGGER_X_HI = 375         # right edge; fruit enters from the right, so widening this triggers earlier
# --- 2a. a smaller box for unripe fruit ---
#   The model detects unripe fruit on almost every frame, so the debounce fills
#   immediately at the entry edge and the plate fires too early. Pulling the entry
#   edges inward makes the fruit travel further before it triggers.
TRIGGER_X_HI_UNRIPE = 335  # 40 px inside the normal edge
TRIGGER_Y_HI_UNRIPE = 455  # 35 px inside the normal edge
COUNT_GAP       = 1.5       # a class must be absent from the box this long before the next detection counts as a new piece of fruit
TRIGGER_CONFIRM = 3         # consecutive frames required inside the box, which rejects one- and two-frame ghosts

# --- 2b. fresh veto ---
#   The model often mislabels fresh fruit as rotten or unripe, but rarely the other
#   way round. So a 'fresh' label is the trustworthy one: a single fresh detection
#   inside the box blocks the servo for a while, protecting good fruit from being
#   rejected. The veto needs one frame while a reject needs several, so fresh wins.
FRESH_VETO      = True       # set False to make every class trigger independently
FRESH_VETO_TIME = 2.0        # roughly how long one piece of fruit takes to cross the box

# --- miscellaneous ---
MIN_CONFIDENCE     = 50      # ignore detections below this; 0 disables the check
LED_ON_TIME        = 1.0     # seconds an LED stays lit after a detection
#  Duplicate suppression is edge triggered rather than a cooldown: the plate acts
#  once when fruit first enters the box, and re-arms only after it has left.
END_SESSION_TIMEOUT = 30.0   # silence for this long ends the run: final totals to
                             #   the LCD, all LEDs off

# --- debug aid for tuning ---
#   Prints the coordinates of every valid detection regardless of the gate, so the
#   trigger box can be measured by running fruit down the belt and watching how
#   the numbers move. Turn it off afterwards, or it floods the console.
#
DEBUG_COORDS = True

# ============================================================
# IPC send, calling IPC_Example.py as a subprocess
#   A lock serialises access, since concurrent writes to the device clash.
# ============================================================
IPC_EXAMPLE_PATH = "/home/topst/Fabless_Education_blink/Step_0/IPC_Example.py"
_ipc_lock = threading.Lock()

def send_ipc(can_id, data_hex):
    """Send a CAN message to the R5 core. Calls are serialised."""
    cmd = ["sudo", "python3", IPC_EXAMPLE_PATH,
           "snd", "--canID", f"0x{can_id:03X}", "--sndDataHex", data_hex]
    with _ipc_lock:
        try:
            result = subprocess.run(cmd, capture_output=True, text=True, timeout=5)
            if result.returncode != 0:
                print(f"  [ipc error] id=0x{can_id:03X} {result.stderr.strip()}")
        except subprocess.TimeoutExpired:
            print(f"  [ipc error] id=0x{can_id:03X} timed out")

def set_led(led_id, on):
    """Set one LED without blocking. The IPC call goes to its own thread so it
    cannot delay a servo command; the motor always takes priority."""
    run_async(send_ipc, CAN_ID_LED_CONTROL, f"{led_id:02X}{(1 if on else 0):02X}")

def all_led_off():
    send_ipc(CAN_ID_LED_CONTROL, "0000")   # id 0 turns everything off

# One colour per class, each with its own timer, so several can be lit at once.
CLASS_LED = {CLASS_ROTTEN: LED_RED, CLASS_UNRIPE: LED_YELLOW, CLASS_FRESH: LED_GREEN}
_led_timers = {}             # class_id → threading.Timer
_led_on = set()              # currently lit, so the same command is not resent every frame
_led_lock = threading.Lock()

def _led_off(class_id):
    led = CLASS_LED.get(class_id)
    with _led_lock:
        _led_timers.pop(class_id, None)
        was_on = led in _led_on
        _led_on.discard(led)
    if led is not None and was_on:
        set_led(led, False)

def led_pulse(class_id):
    """Light the colour for this class immediately and clear it after LED_ON_TIME.
    Continued detections refresh the timer without resending anything, and each
    class keeps its own timer."""
    led = CLASS_LED.get(class_id)
    if led is None:
        return
    with _led_lock:
        old = _led_timers.get(class_id)
        if old is not None:
            old.cancel()
        nt = threading.Timer(LED_ON_TIME, _led_off, args=(class_id,))
        nt.daemon = True
        _led_timers[class_id] = nt
        nt.start()
        need_on = led not in _led_on
        if need_on:
            _led_on.add(led)
    if need_on:
        set_led(led, True)   # only on the transition, not every frame

def all_leds_clear():
    """Turn every LED off and clear the timers."""
    with _led_lock:
        for t in _led_timers.values():
            t.cancel()
        _led_timers.clear()
        _led_on.clear()
    all_led_off()

# ============================================================
# running totals
# ============================================================
class FruitStats:
    def __init__(self):
        self.total = 0
        self.fresh = 0
        self.rotten = 0
        self.unripe = 0
        self._lock = threading.Lock()

    def record(self, class_id):
        with self._lock:
            self.total += 1
            if class_id == CLASS_FRESH:
                self.fresh += 1
            elif class_id == CLASS_ROTTEN:
                self.rotten += 1
            elif class_id == CLASS_UNRIPE:
                self.unripe += 1

    def lcd_hex(self):
        """Four bytes for the LCD: total, fresh, rotten, unripe."""
        with self._lock:
            return (f"{min(self.total,255):02X}"
                    f"{min(self.fresh,255):02X}"
                    f"{min(self.rotten,255):02X}"
                    f"{min(self.unripe,255):02X}")

    def line(self):
        with self._lock:
            t = self.total or 1
            return (f"total:{self.total} | fresh:{self.fresh}({self.fresh*100//t}%) | "
                    f"rotten:{self.rotten}({self.rotten*100//t}%) | "
                    f"unripe:{self.unripe}({self.unripe*100//t}%)")

stats = FruitStats()
_armed = {CLASS_FRESH: True, CLASS_ROTTEN: True, CLASS_UNRIPE: True}  # edge trigger, per class
_inwin = {CLASS_FRESH: 0, CLASS_ROTTEN: 0, CLASS_UNRIPE: 0}           # consecutive frames inside the box
_box_last = {CLASS_FRESH: 0.0, CLASS_ROTTEN: 0.0, CLASS_UNRIPE: 0.0}  # last seen, used to re-arm
_fresh_veto_until = 0.0  # rejects are blocked until this time
_last_detect  = 0.0      # timestamp of the last detection
_session_active = False  # so the end-of-run actions happen exactly once
_end_lock = threading.Lock()

def update_lcd():
    """Push the totals to the LCD. Only called when a run ends."""
    send_ipc(CAN_ID_LCD_STATS, stats.lcd_hex())

def end_watcher():
    """After END_SESSION_TIMEOUT seconds with no detection, treat the run as
    finished: show the totals on the LCD and turn the LEDs off."""
    global _session_active
    while True:
        time.sleep(1.0)
        with _end_lock:
            active = _session_active
            idle = time.time() - _last_detect
        if active and idle >= END_SESSION_TIMEOUT:
            print(f"\n===== run finished, {END_SESSION_TIMEOUT:.0f}s with no detection =====")
            print(f"  final: {stats.line()}")
            update_lcd()        # totals to the LCD
            all_leds_clear()
            with _end_lock:
                _session_active = False
            if ORCHESTRATE:                     # also stop the AI board and exit
                stop_aig()
                servo_angle(SERVO_DEFAULT_DEG)
                print("[exit] no detections for 30 s, shutting down")
                os._exit(0)

# ============================================================
# tilt plate servo
# ============================================================
def servo_angle(deg):
    """Move the plate to the given angle. Byte 0 of the frame is the angle."""
    deg = max(0, min(180, int(deg)))
    send_ipc(SERVO_CAN_ID, f"{deg:02X}")

_servo_lock = threading.Lock()   # one plate, so one movement at a time

def servo_sort(angle, name):
    """Tilt, hold, return to level.
    Triggers that arrive while the plate is moving are dropped rather than queued.
    A queue would make the plate act late, on the wrong piece of fruit."""
    if not _servo_lock.acquire(blocking=False):
        print(f"  -> [{name}] plate already moving, dropped")
        return
    try:
        print(f"  -> [{name}] {SERVO_DEFAULT_DEG} to {angle}, hold {SERVO_HOLD_TIME}s, back to {SERVO_DEFAULT_DEG}")
        servo_angle(angle)
        time.sleep(SERVO_HOLD_TIME)
        servo_angle(SERVO_DEFAULT_DEG)
    finally:
        _servo_lock.release()

def run_async(fn, *args):
    """Run in a thread so the hold time does not block the TCP receive loop."""
    threading.Thread(target=fn, args=args, daemon=True).start()

# ============================================================
# handle one detection
#   wire format: "CLASS:1,CONF:85,X:300,Y:400,W:0,H:0"
#   The plate acts when the coordinates fall inside the trigger box.
# ============================================================
def process_detection(msg):
    global _last_detect, _session_active, _fresh_veto_until
    try:
        parts = dict(item.split(':') for item in msg.split(','))
        class_id   = int(parts['CLASS'])
        confidence = int(parts.get('CONF', 0))
        cx         = float(parts.get('X', -1))             # centre x, pixels
        cy         = float(parts.get('Y', -1))             # centre y, along the belt
    except (ValueError, KeyError) as e:
        print(f"[error] could not parse: {msg} ({e})")
        return

    name = CLASS_NAMES.get(class_id)
    if name is None:
        return                                   # unknown class
    if MIN_CONFIDENCE > 0 and confidence < MIN_CONFIDENCE:
        return                                   # below the confidence floor

    # tuning aid: print every valid detection
    if DEBUG_COORDS:
        print(f"[coords] {name:>6s} conf={confidence:3d}%  "
              f"X={parts.get('X','?')}  Y={parts.get('Y','?')}")

    # mark the run as active and refresh the end-of-run timer
    now = time.time()
    with _end_lock:
        _last_detect = now
        _session_active = True

    # Box gate plus edge trigger. Fruit that enters the box counts once, however
    # many frames it is detected on. The class re-arms only after it has been
    # absent from the box for COUNT_GAP seconds, which means the fruit has left.
    # Both axes must be inside, because the belt runs diagonally.
    # Unripe uses the smaller box; it is over-detected and otherwise fires too early.
    if class_id == CLASS_UNRIPE:
        x_hi, y_hi = TRIGGER_X_HI_UNRIPE, TRIGGER_Y_HI_UNRIPE   # entry edges pulled in
    else:
        x_hi, y_hi = TRIGGER_X_HI, TRIGGER_Y_HI
    in_box = (TRIGGER_X_LO <= cx <= x_hi) and (TRIGGER_Y_LO <= cy <= y_hi)

    # Ghost rejection: count up inside the box, down outside. Only a sustained run counts.
    if in_box:
        _inwin[class_id] = min(_inwin[class_id] + 1, TRIGGER_CONFIRM + 3)
    else:
        _inwin[class_id] = max(_inwin[class_id] - 1, 0)

    # Re-arm once the class has been absent long enough that the fruit must have left.
    # Re-detections and jitter fall inside the gap and do not count again.
    if in_box:
        _box_last[class_id] = now
    elif now - _box_last.get(class_id, 0.0) >= COUNT_GAP:
        _armed[class_id] = True

    # A fresh detection inside the box blocks rejects for a while
    if FRESH_VETO and class_id == CLASS_FRESH and in_box:
        if now >= _fresh_veto_until:
            print(f"  [veto] fresh detected, servo blocked for {FRESH_VETO_TIME:.1f}s")
        _fresh_veto_until = now + FRESH_VETO_TIME

    # while the veto is active, treat this piece as fresh and let it pass
    if (FRESH_VETO and class_id in (CLASS_ROTTEN, CLASS_UNRIPE)
            and now < _fresh_veto_until):
        if in_box and _armed.get(class_id, True) and _inwin[class_id] >= TRIGGER_CONFIRM:
            _armed[class_id] = False
            print(f"  [veto] ignoring {name}, treating as fresh")
        return   # no servo, no count, no LED

    if in_box and _armed.get(class_id, True) and _inwin[class_id] >= TRIGGER_CONFIRM:
        _armed[class_id] = False                  # disarm until the fruit leaves
        # dispatch the servo before the LED, so nothing delays the motor
        if class_id == CLASS_ROTTEN:
            run_async(servo_sort, SERVO_LEFT_DEG, "rotten, left")
        elif class_id == CLASS_UNRIPE:
            run_async(servo_sort, SERVO_RIGHT_DEG, "unripe, right")
        stats.record(class_id)
        print(f"\n[detect] {name} ({confidence}% confidence, x={cx:.0f} y={cy:.0f})")
        if class_id == CLASS_FRESH:
            print("  -> fresh: plate stays level, passes through")
        print(f"  [totals] {stats.line()}")    # the LCD only updates at the end

    # LED last, and non-blocking, so it never delays the motor
    led_pulse(class_id)

# ============================================================
# main: TCP server
# ============================================================
def main():
    print("=" * 60)
    print("  strawberry sorting - controller (single servo, position triggered)")
    print(f"  angles: fresh {SERVO_DEFAULT_DEG} / rotten {SERVO_LEFT_DEG} / "
          f"unripe {SERVO_RIGHT_DEG}, hold {SERVO_HOLD_TIME}s")
    print(f"  trigger box: X {TRIGGER_X_LO}-{TRIGGER_X_HI} and Y {TRIGGER_Y_LO}-{TRIGGER_Y_HI}, {TRIGGER_CONFIRM} frames, hold {SERVO_HOLD_TIME}s")
    print(f"  unripe box: X {TRIGGER_X_LO}-{TRIGGER_X_HI_UNRIPE} and Y {TRIGGER_Y_LO}-{TRIGGER_Y_HI_UNRIPE}")
    if FRESH_VETO:
        print(f"  fresh veto on: one fresh detection blocks the servo for {FRESH_VETO_TIME:.1f}s")
    print("  the conveyor is externally controlled")
    print(f"  LEDs light on detection, LCD shows totals at the end after {END_SESSION_TIMEOUT:.0f}s of silence")
    if ORCHESTRATE:
        print(f"  orchestration on: the AI board at {AIG_IP} is driven over SSH")
    print("=" * 60)

    # pin the local ethernet address
    if SETUP_D3G_NET:
        setup_d3g_net()

    # start clean: LEDs off, plate level; the LCD keeps its ready message
    all_led_off()
    servo_angle(SERVO_DEFAULT_DEG)

    # watchdog thread that ends the run after a period of silence
    threading.Thread(target=end_watcher, daemon=True).start()

    server = socket.socket(socket.AF_INET, socket.SOCK_STREAM)
    server.setsockopt(socket.SOL_SOCKET, socket.SO_REUSEADDR, 1)
    server.bind(("0.0.0.0", AI_G_PORT))
    server.listen(1)
    print(f"\n[tcp] waiting for the AI board on port {AI_G_PORT}")

    # start recognition only once the socket is listening
    if ORCHESTRATE:
        time.sleep(0.5)
        start_aig()

    try:
        while True:
            client, addr = server.accept()
            print(f"[tcp] connected: {addr}")
            buffer = ""
            try:
                while True:
                    data = client.recv(1024).decode('utf-8')
                    if not data:
                        print("[tcp] disconnected")
                        break
                    buffer += data
                    while '\n' in buffer:
                        line, buffer = buffer.split('\n', 1)
                        if line.strip():
                            process_detection(line.strip())
            except Exception as e:
                print(f"[tcp] receive error: {e}")
            finally:
                client.close()
    except KeyboardInterrupt:
        print("\n[exit] shutting down")
    finally:
        if ORCHESTRATE:
            stop_aig()
        # return the plate to level and clear the LEDs
        servo_angle(SERVO_DEFAULT_DEG)
        all_led_off()
        update_lcd()          # totals on every exit path, including Ctrl-C
        print("\n===== final totals =====")
        print(stats.line())
        server.close()

if __name__ == "__main__":
    main()

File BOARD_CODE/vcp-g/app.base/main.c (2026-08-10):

// SPDX-License-Identifier: Apache-2.0

/*
***************************************************************************************************
*
* FileName : main.c
*
* Copyright (c) Telechips Inc.
*
* Description :
*
*
***************************************************************************************************
*/

#if ( MCU_BSP_SUPPORT_APP_BASE == 1 )

#include <main.h>

#include <sal_api.h>
#include <app_cfg.h>
#include <debug.h>
#include <bsp.h>
#include "lcd1602.h"

#if (APLT_LINUX_SUPPORT_SPI_DEMO == 1)
    #include <spi_eccp.h>
#endif
#if (APLT_LINUX_SUPPORT_POWER_CTRL == 1)
    #include <power_app.h>
#endif
#if ( MCU_BSP_SUPPORT_APP_KEY == 1)
    #include <key.h>
#endif  // ( MCU_BSP_SUPPORT_APP_KEY == 1 )

#if ( MCU_BSP_SUPPORT_APP_CONSOLE == 1 )
    #include <console.h>
#endif  // ( MCU_BSP_SUPPORT_APP_CONSOLE == 1 )

#if ( MCU_BSP_SUPPORT_CAN_DEMO == 1 )
    #include <can_demo.h>
#endif  // ( MCU_BSP_SUPPORT_CAN_DEMO == 1 )

#if ( MCU_BSP_SUPPORT_APP_IDLE == 1 )
    #include <idle.h>
#endif  // ( MCU_BSP_SUPPORT_APP_IDLE == 1 )

#if ( MCU_BSP_SUPPORT_APP_SPI_LED == 1 )
    #include <spi_led.h>
#endif  // ( MCU_BSP_SUPPORT_APP_SPI_LED == 1 )

#if ( MCU_BSP_SUPPORT_APP_FW_UPDATE == 1 )
    #include "fwupdate.h"
#elif ( MCU_BSP_SUPPORT_APP_FW_UPDATE_ECCP == 1 )
    #include "fwupdate.h"
#endif

/*
***************************************************************************************************
* GLOBAL VARIABLES
***************************************************************************************************
*/
uint32                                  gALiveMsgOnOff;
static uint32                           gALiveCount;

/*
***************************************************************************************************
* FUNCTION PROTOTYPES
***************************************************************************************************
*/

static void Main_StartTask
(
    void * pArg
);

static void AppTaskCreate
(
    void
);

static void DisplayAliveLog
(
    void
);

static void DisplayOTPInfo
(
    void
);


/*
***************************************************************************************************
* FUNCTIONS
***************************************************************************************************
*/
/*
***************************************************************************************************
* cmain
*
* This is the standard entry point for C code.
*
* Notes
* It is assumed that your code will call main() once you have performed all necessary
* initialization.
*
***************************************************************************************************
*/
void cmain (void)
{
    static uint32           AppTaskStartID = 0;
    static uint32           AppTaskStartStk[ACFG_TASK_MEDIUM_STK_SIZE];
    SALRetCode_t            err;
    SALMcuVersionInfo_t     versionInfo = {0,0,0,0};

    (void)SAL_Init();

    BSP_PreInit(); /* Initialize basic BSP functions */

#if ( MCU_BSP_SUPPORT_CAN_DEMO == 1 )
    (void)CAN_DemoInitialize();
#endif  // ( MCU_BSP_SUPPORT_CAN_DEMO == 1 )

    BSP_Init(); /* Initialize BSP functions */

    (void)SAL_GetVersion(&versionInfo);
    mcu_printf("\n===============================\n");
    mcu_printf("    MCU BSP Version: V%d.%d.%d\n",
            versionInfo.viMajorVersion,
            versionInfo.viMinorVersion,
            versionInfo.viPatchVersion);
    mcu_printf("-------------------------------\n");
    DisplayOTPInfo();
    mcu_printf("===============================\n\n");

    // create the first app task...
    err = (SALRetCode_t)SAL_TaskCreate(&AppTaskStartID,
                         (const uint8 *)"App Task Start",
                         (SALTaskFunc) &Main_StartTask,
                         &AppTaskStartStk[0],
                         ACFG_TASK_MEDIUM_STK_SIZE,
                         SAL_PRIO_APP_CFG,
                         NULL);

    if (err == SAL_RET_SUCCESS)
    {
        // start woring os.... never return from this function
        (void)SAL_OsStart();
    }
}

/*
***************************************************************************************************
* Main_StartTask
*
* This is an example of a startup task.
*
* Notes
* As mentioned in the book's text, you MUST initialize the ticker only once multitasking has
* started.
*
* 1) The first line of code is used to prevent a compiler warning because 'pArg' is not used.
* The compiler should not generate any code for this statement.
*
***************************************************************************************************
*/
static void Main_StartTask (void * pArg)
{
    (void) pArg;
    (void) SAL_OsInitFuncs();

    // create the system tasks, including the sorting task
    AppTaskCreate();

    // The LCD is owned entirely by can_vcp_ctrl.
    // The SDK demo was removed: it printed its own banner and re-initialised I2C,
    // which fought with can_vcp_ctrl over the bus.
    while (1) {
        (void) SAL_TaskSleep(1000);
    }
}

static void AppTaskCreate(void)
{
#if (APLT_LINUX_SUPPORT_SPI_DEMO == 1)
    ECCP_InitSPIManager();
#endif  
#if (APLT_LINUX_SUPPORT_POWER_CTRL == 1)
    POWER_APP_StartDemo();
#endif

  
#if ( MCU_BSP_SUPPORT_APP_CONSOLE == 1 )
    CreateConsoleTask();
#endif  // ( MCU_BSP_SUPPORT_APP_CONSOLE == 1 )

#if ( MCU_BSP_SUPPORT_APP_KEY == 1 )
    KEY_AppCreate();
#endif  // ( MCU_BSP_SUPPORT_APP_KEY == 1 )

#if ( MCU_BSP_SUPPORT_CAN_DEMO == 1 )
    CAN_DemoCreateApp();
#endif  // ( MCU_BSP_SUPPORT_CAN_DEMO == 1 )

#if ( MCU_BSP_SUPPORT_APP_FW_UPDATE == 1 )
    CreateFWUDTask();
#elif ( MCU_BSP_SUPPORT_APP_FW_UPDATE_ECCP == 1 )
    CreateFWUDTask();
#endif

#if ( MCU_BSP_SUPPORT_APP_IDLE == 1 )
    IDLE_CreateTask();
#endif  // ( MCU_BSP_SUPPORT_APP_IDLE == 1 )

#if ( MCU_BSP_SUPPORT_APP_SPI_LED == 1)
    SPILED_CreateAppTask();
#endif  // ( MCU_BSP_SUPPORT_APP_SPI_LED == 1 )

}

static void DisplayAliveLog(void)
{
    if (gALiveMsgOnOff != 0U)
    {
        mcu_printf("\n %d", gALiveCount);

        gALiveCount++;

        if(gALiveCount >= MAIN_UINT_MAX_NUM)
        {
            gALiveCount = 0;
        }
    }
    else
    {
        gALiveCount = 0;
    }
}

#define LDT1_AREA_ADDR  0xA1011800U
#define PMU_REG_ADDR    0xA0F28000U
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
